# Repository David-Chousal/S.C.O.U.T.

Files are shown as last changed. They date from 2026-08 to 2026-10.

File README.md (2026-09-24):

# S.C.O.U.T.



**Santa Clara Oceanic Utilities Transmitter** — a low-cost, solar-powered, modular
**nearshore environmental monitoring platform**: one buoy carrying many sensing signals
(temperature, turbidity, dissolved oxygen, and more), with coral-reef health as its first
application.

Santa Clara University · Senior Design Capstone · 2026–2027

---

## What S.C.O.U.T. is

Coral reefs are among the most threatened ecosystems on Earth, and the instruments used to
monitor them are expensive and rarely serviced. Existing monitoring buoys cost tens of
thousands of dollars, and researchers interviewed for this project described sites where data
is physically retrieved only every few years.

S.C.O.U.T. is a small, modular, solar-powered buoy designed to be deployed adjacent to shallow
reefs and left alone. It samples a stack of environmental signals — water temperature and
turbidity today, with dissolved oxygen, light, chlorophyll, and reef soundscapes on the
sensor roadmap — stores everything locally, and transmits a summarized daily packet to a
shore station over LoRa radio, with no cellular service or internet required at the buoy.

It is deliberately built as a **platform, not a single-purpose instrument**: the sensing
payload is modular so the same buoy, power system, and shore link can be re-tasked across
reef monitoring, water-quality tracking, and satellite ground-truthing. Coral reef health is
the first mission, not the boundary. See the
[MVP System Overview](docs/overview/mvp-system-overview.md) and
[Sensor Selection](docs/engineering/sensor-selection.md) for the signal roadmap.

**Design priorities:** affordable · durable · low power · modular · minimal maintenance ·
scalable to many signals, many buoys, and many sites.

**Target:** autonomous operation for 1+ year deployments at a total system cost well below
the $5,000 figure researchers identified as the practical ceiling.

### What makes it different

Stakeholder interviews with three NOAA coral reef researchers pointed consistently at the
same gap: the highest-value contribution is not replacing existing monitoring systems, but
providing **affordable, accessible ground-truth measurements** — particularly in shallow
nearshore water, where satellite products degrade badly due to bottom reflectance and coastal
complexity. See [Stakeholder Interviews](docs/research/stakeholder-interviews.md).

---

## Status

| Subsystem | Status |
|---|---|
| Stakeholder research | ✅ Complete — 3 NOAA researchers interviewed |
| System architecture | ✅ Complete — [Engineering Design Document v0.2](docs/engineering/engineering-design-document.md) |
| Acoustic analysis pipeline | ✅ Working — validated on 8 sessions of reef recordings |
| Environmental telemetry pipeline | ✅ Working — QC, NOAA CRW Degree Heating Weeks + bleaching alerts, trends, and turbidity anomalies ([`analytics/telemetry/`](analytics/telemetry/)) |
| Firmware | 🟡 Phase 1 in progress — state machine, drivers, verified packet codec + scheduler, standby sleep, watchdog, and battery-tiered adaptive transmission; hardware bring-up next ([`firmware/`](firmware/README.md)) |
| Shore station | 🟡 In progress — simulated LoRa→CSV data path (packet codec, receiver, store) with tests ([`shore/`](shore/README.md)); real radio bring-up next |
| Live dashboard | 🟢 Deployed — static [GitHub Pages telemetry dashboard](docs/engineering/live-dashboard.md) (sample data) |
| Ask S.C.O.U.T. chat | 🟢 Live — "Fred" widget backed by a Cloudflare Worker proxy, answers from the published Hub context ([`chatbot/`](chatbot/README.md)) |
| Electrical design | 🟡 In progress — build platform decided ([ADR-0001](docs/decisions/0001-mcu-and-radio-selection.md)); charging path ([ADR-0002](docs/decisions/0002-lifepo4-charging-path.md)) and wiring/PCB pending |
| Mechanical design | 🟡 In progress — all five CAD categories documented ([SCO-50](https://linear.app/scout1/issue/SCO-50)): floatation, electronics housing, sensor/turbidity pod, stem, solar mount, in [`mechanical/cad/`](mechanical/cad/). Floatation family chosen 2026-08-17 (bolted wedge + bottom caps), first FEA pass complete ([`mechanical/test/`](mechanical/test/)). Open: buoyancy check, housing dimensions, chassis top-section access, mooring attachment hardware |
| Field deployment | 🔴 Planned — Hawaii, Phase 6 (Mar–May 2027) |

**Latest decision:** the microcontroller and LoRa radio are now settled — **Feather M0 +
RFM95 (Adafruit 3178)** as the confirmed build platform, with the ESP32-C3 + SX1262 retained
as the future production-PCB target. This unblocks firmware and wiring. See
[ADR-0001](docs/decisions/0001-mcu-and-radio-selection.md).

---

## Team

| Member | Discipline | Role |
|---|---|---|
| Isabella Rodriguez | ECEN | Hardware lead — electrical design, PCB, power system |
| John Ryan Myrdal | GENG | Field & mechanical lead — buoy structure, deployment |
| David Chousal Cantu | CSEN | Software lead — firmware, data pipeline, shore station |

**Faculty advisors:** Jes Kuczenski · Hoeseok Yang (ECEN) · Navid Shaghaghi

---

## Repository layout

```
S.C.O.U.T./
├── docs/           All project documentation (Notion-compatible Markdown)
│   ├── hub/            Knowledge Hub — facts, decisions, status, research library
│   ├── overview/       Project vision, MVP definition, status updates
│   ├── engineering/    Design document, sensor selection, architecture, shore station
│   ├── research/       Stakeholder interviews, decision matrix
│   ├── analysis/       Bioacoustic + telemetry methodology and citations
│   ├── planning/       Timeline, meeting notes, administrative
│   └── decisions/      Architecture Decision Records
├── analytics/      Acoustic + environmental-telemetry pipelines (Python) — implemented
├── shore/          Shore-station receiver, store, and packet codec (Python) — simulated path working
├── firmware/       Buoy embedded software (SAMD21/PlatformIO) — Phase 1 in progress
├── hardware/       Schematics, PCB, wiring diagrams — build platform + BOM confirmed, no schematics/PCB files yet
├── mechanical/     CAD, hull design, mooring specs — all five CAD categories documented
├── chatbot/        "Ask S.C.O.U.T." chat widget (Cloudflare Worker + Groq) — deployed
├── assets/         Brand, diagrams, and presentations
├── scripts/        Repo-level helper scripts (e.g. cross-language packet-contract guard)
└── data/           Raw audio archive (excluded from git — see Data below)
```

Each subsystem directory has its own README describing scope, current status, and what
it is blocked on.

---

## Quick start

Several components run today with no hardware: the two analytics pipelines and the shore-station
data path.

**Acoustic pipeline** — five bioacoustic indices → PCA health score → dashboard figure, on the
committed sample session:

```bash
cd analytics
pip install -r requirements.txt
python run_pipeline.py --audio_dir data/longitudinal/201708_20170801 \
                       --output data/processed/results.csv
```

**Shore data path + environmental telemetry** — simulate a buoy, push the packets through the shore
receiver into daily CSVs, then analyze them (QC, NOAA CRW Degree Heating Weeks, trends, turbidity):

```bash
cd shore
pip install -r requirements.txt
python scripts/run_loopback.py --count 48 --out ./data     # sensor sim → encode → receive → store

cd ../analytics
python run_telemetry.py --source ../shore/data --mmm 27.6 --dashboard
```

See [`analytics/README.md`](analytics/README.md) and [`shore/README.md`](shore/README.md) for the
full options, and the [live telemetry dashboard](docs/engineering/live-dashboard.md) for the deployed view.

---

## System architecture

```
   ┌─────────────────────────── BUOY ───────────────────────────┐
   │                                                            │
   │  Solar panel ──► MPPT charger ──► LiFePO₄ battery          │
   │                                        │                   │
   │                                        ▼                   │
   │  Temperature (DS18B20 ×1) ──┐    Microcontroller           │
   │  Turbidity  (SEN0189 ×1) ───┼──►  duty-cycle state machine │
   │  Hydrophone (Aquarian) ─────┘     sleep / sense / log / TX │
   │                                        │                   │
   │                          Onboard flash ┤                   │
   │                                        ▼                   │
   │                                   LoRa radio               │
   └────────────────────────────────────────┼───────────────────┘
                                            │  30-byte packet, 1×/day
                                            ▼
                        ┌─────────── SHORE STATION ───────────┐
                        │  Raspberry Pi receiver              │
                        │  Packet validation → storage        │
                        │  Statistical processing             │
                        │  Future: dashboards, cloud, ML      │
                        └─────────────────────────────────────┘
```

**Sensing.** One sensor of each modality is sited at a single point beneath the buoy, with the
electronics bay sealed above the waterline; spare temperature and turbidity units are kept for
field replacement ([ADR-0003](docs/decisions/0003-single-point-sensing.md)). A vertical
multi-depth string — measuring thermal and turbidity stratification — is a documented future
concept, not the current build. See [Sensor String Architecture](docs/engineering/sensor-string-architecture.md).

**Power.** The system sleeps most of the time, waking on an RTC alarm to sample, log, and
periodically transmit. Under sustained cloud cover it degrades gracefully: transmission
frequency drops first, local logging continues, and nonessential sensing pauses before core
operation is compromised.

**Communications.** A single summarized 30-byte packet per day (82 B is the EDD budget ceiling). Raw audio is **stored onboard
and never transmitted** — moving waveform data over LoRa is not bandwidth-feasible, and this
constraint is baked into the design.

---

## The acoustic pipeline

The [`analytics/`](analytics/README.md) pipeline is the most mature part of the project. It
processes 5-minute hydrophone recordings into reef health indicators using five established
bioacoustic indices (ACI, BI, NDSI, H, ADI), reduces them via PCA to a single Acoustic
Quality Score, and applies modified Mann-Kendall tests to detect multi-month trends.

It was developed and validated against a published reef acoustic dataset from **Sesoko
Island, Okinawa, Japan** — 8 monthly sessions spanning August 2017 to July 2018 — which
serves as a stand-in until S.C.O.U.T. collects its own recordings.

Notable design choices, documented in full in
[Coral Bioacoustic Methodology](docs/analysis/coral-bioacoustic-methodology.md):

- A **three-zone frequency model** that carves out a 200–1000 Hz mixed band and excludes it
  from NDSI, because the conventional two-way split misclassified reef fish choruses as
  anthropogenic noise.
- **Session-local PCA** for health scoring, with a separately fit global PCA for longitudinal
  trend detection — scores are explicitly not comparable across sessions.
- **Median aggregation** and an **abiotic contamination filter** to stay robust against
  wind- and rain-contaminated recordings at 1.5 m depth.

---

## The environmental telemetry pipeline

Alongside the acoustic work, [`analytics/telemetry/`](analytics/telemetry/) turns the buoy's daily
CSV records into reef-relevant indicators. It quality-controls the series (QARTOD-style range, spike,
flat-line, and gap flags), computes **NOAA Coral Reef Watch thermal-stress metrics** — HotSpot,
Degree Heating Weeks, and the 4/8/12 °C-week bleaching alert levels — detects multi-month temperature
and turbidity trends with modified Mann-Kendall, and flags turbidity anomalies. Run it with
`run_telemetry.py`; the method is written up in
[Environmental Telemetry Methodology](docs/analysis/telemetry-methodology.md), and the external
research behind it (DHW, turbidity, LoRa-over-saltwater) lives in the
[Knowledge Hub research library](docs/hub/research/sources.md).

The [`shore/`](shore/README.md) package closes the loop: a packet codec (byte-identical to the
firmware), a simulated LoRa link with configurable loss and corruption, a receiver, and a daily CSV
store — so the whole buoy → shore → analysis path runs today without hardware.

---

## Data

The raw audio archive is roughly 7 GB and is **not tracked in git**.

| What | Where | Tracked |
|---|---|---|
| Sample session (5 × 5-min WAV, ~252 MB) | `analytics/data/longitudinal/201708_20170801/` | ✅ Yes — so the pipeline is runnable on clone |
| Full 8-session archive | `analytics/data/longitudinal/` | ❌ Excluded by size |
| Bulk raw archive | `data/` | ❌ Excluded by size |
| Generated results and figures | `analytics/data/processed/` | ✅ Yes |

The full dataset is publicly available from its original authors — see the dataset citation
in [Coral Bioacoustic Methodology](docs/analysis/coral-bioacoustic-methodology.md#data-sources).
`analytics/utils/download_sesoko.py` assists with retrieval.

**Known gap:** session `201807` has 4 of 5 files; one recording failed to download. The
pipeline handles short sessions by taking the median of what is present.

---

## Documentation

Full index at [`docs/README.md`](docs/README.md). All documentation is Notion-compatible
Markdown and can be imported directly.

| Document | Why you'd read it |
|---|---|
| **[Knowledge Hub](docs/hub/README.md)** | **What's true, decided, and where the project stands right now — the always-current surface** |
| **[Conventions](docs/CONVENTIONS.md)** | **Where files go, what to name them, formats, git, units — start here before adding anything** |
| [MVP System Overview](docs/overview/mvp-system-overview.md) | What S.C.O.U.T. is and what it must do |
| [Engineering Design Document](docs/engineering/engineering-design-document.md) | The authoritative technical baseline — 22 sections including full BOM |
| [Stakeholder Interviews](docs/research/stakeholder-interviews.md) | What reef researchers actually need |
| [Coral Bioacoustic Methodology](docs/analysis/coral-bioacoustic-methodology.md) | The science behind the acoustic analysis |
| [Team Timeline](docs/planning/team-timeline.md) | Phase 0–6 plan through Hawaii deployment |
| [Decision Records](docs/decisions/README.md) | Significant open and settled decisions |

---

## Known inconsistencies

Surfaced during the August 2026 documentation audit. Resolved items are struck through with
their resolution; the remaining open ones are marked ⏳ with an owner. Recorded here rather
than silently reconciled, since resolving each required a team decision.

> The settled values now live in [`docs/hub/facts.md`](docs/hub/facts.md) (canonical) and the
> open ones in [`facts.md` → Open facts](docs/hub/facts.md#open-facts-deliberately-not-settled-yet).
> This table is the historical audit record; `facts.md` is what to check going forward.

| Issue | Detail |
|---|---|
| ~~**MCU and radio**~~ ✅ Resolved | Settled by [ADR-0001](docs/decisions/0001-mcu-and-radio-selection.md): Feather M0 + RFM95 is the build platform; ESP32-C3 + SX1262 is the future production target |
| ~~**Deployment depth**~~ ✅ Resolved | **2–8 m** max, confirmed against the actual Hawaii site (was 5–8 m). The ~30 m on the sensor-string diagram image is outdated — PNG needs re-exporting |
| ~~**LoRa range**~~ ✅ Resolved | Standardized to **~2 km line of sight** ([Adafruit RFM9x FAQ](https://learn.adafruit.com/adafruit-feather-m0-radio-with-lora-radio-module/radio-range-faq)); ~100 yd and 15–20 km figures corrected. Real over-saltwater range still to be measured in Phase 4 |
| ~~**Sensor count**~~ ✅ Resolved | [ADR-0003](docs/decisions/0003-single-point-sensing.md): one sensor per modality deployed; extra DS18B20/SEN0189 are field spares; multi-depth string deferred |
| **Hydrophone part** ⏳ ECE | Aquarian H2a-XLR (diagram) vs H2dM (BOM). **Owner: Isabella (ECE)** — [SCO-8](https://linear.app/scout1/issue/SCO-8), `Needs Decision` |
| **Dissolved oxygen status** ⏳ ECE | Wanted (meeting notes, interviews), V1.5 in sensor-selection, absent from EDD/BOM. **Owner: Isabella (ECE)** — [SCO-11](https://linear.app/scout1/issue/SCO-11), `Needs Decision` |
| ~~**Academic year**~~ ✅ Resolved | **2026–2027**. No stray 2025–2027 remains in the docs |
| ~~**Project name**~~ ✅ Resolved | **"Oceanic Utilities Transmitter"** (plural) — used consistently across all docs; no "Utility" (singular) instances remain |

---

## Related

- Team repository: [github.com/irodriguez-17/S.C.O.U.T.](https://github.com/irodriguez-17/S.C.O.U.T.)
- Project proposal deck: [`assets/presentations/SCOUT-Proposal.pptx`](assets/presentations/)

## License

Released under the [MIT License](LICENSE). Copyright (c) 2026 David Chousal Cantu,
Isabella Rodriguez, John Ryan Myrdal.

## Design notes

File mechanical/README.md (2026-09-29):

# Mechanical — Buoy Structure & Marine Design

CAD models, hull design, enclosure drawings, mooring specifications, and field test records.

> **Status:** All five CAD categories populated — floatation, electronics housing,
> sensor/turbidity housing, stem, solar mount (49 STEP/PDF files total, see
> [`cad/README.md`](cad/README.md)). **Floatation family chosen 2026-08-17** — bolted wedge
> variant with bottom caps ([`cad/floatation/README.md`](cad/floatation/README.md)), first FEA
> pass complete ([`test/`](test/README.md)). **Chassis cap + wedge cap added 2026-08-20**
> (first pass at the [SCO-53](https://linear.app/scout1/issue/SCO-53) cable-gland cap revision;
> cable routing and cap OD still open). **Design panel review 2026-08-21** — architecture
> confirmed, proceed to detailed design ([full write-up](../docs/engineering/reviews/buoy-preliminary-design-panel-review-2026-08.md)).
> Dimensioned v4 drawings (wedge, wedge cap, wedge bottom, chassis, chassis cap) landed the
> same day, giving a first-pass [mass/buoyancy budget](../docs/engineering/buoy-structural/mass-and-buoyancy-budget.md)
> and confirming the buoy's overall diameter at 18 in. **All five parts now have real
> slicer-measured weights (2026-08-24)** — whole shell ~5.49 kg, ~337.6 N net reserve buoyancy;
> see [`test/print-weight-verification-2026-08-24.md`](test/print-weight-verification-2026-08-24.md).
> **First waterproofing submersion test, 2026-08-24** — PLA sensor housing + TPU-printed O-ring
> passed ~30 hr submerged; PETG (low print quality) and the electronics housing (no bolt-joint
> washers on the tested article) both failed, see
> [`test/waterproofing-submersion-test-2026-08-24.md`](test/waterproofing-submersion-test-2026-08-24.md).
> **Electronics housing packing analysis, 2026-08-25** — real component dimensions from
> Isabella's Rev A datasheets, three candidate cylindrical layouts computed, recommended
> ~⌀100 mm × 110–130 mm (fits the existing ~4" PVC reference); see
> [Electronics Housing Packing Budget](../docs/engineering/electronics-housing-packing-budget.md).
> **Electronics housing static face-seal clamp, 2026-09-02** — new clamp + lid pair moving the
> 6 fasteners **outside** the AS568-043 O-ring boundary and sizing the groove to the standard
> ring (22.9 % squeeze, 75 % fill); closes the design panel review's lid-seal finding
> ([SCO-68](https://linear.app/scout1/issue/SCO-68),
> [`cad/electronics-housing/README.md`](cad/electronics-housing/README.md#static-face-seal-clamp--2026-09-02)).
> Printed, slight O-ring tolerance trouble, **reprint pending**
> ([SCO-105](https://linear.app/scout1/issue/SCO-105)). **Declared the housing baseline the same
> day**, superseding the end-cap-into-cylinder scheme.
> Print-structure spec (walls/infill per part) now lives in its own
> [Print Settings](../docs/engineering/buoy-structural/print-settings.md) doc; the actual FEA load values will
> land in [Force Budget](../docs/engineering/buoy-structural/force-budget.md) as their inputs arrive. Still
> open: buoyancy check + PDF-drawing reconciliation on
> [SCO-48](https://linear.app/scout1/issue/SCO-48), housing dimensions
> ([SCO-49](https://linear.app/scout1/issue/SCO-49)), chassis top section — sealing/service
> access ([SCO-68](https://linear.app/scout1/issue/SCO-68)), mooring/sensor-string attachment
> hardware ([SCO-69](https://linear.app/scout1/issue/SCO-69)), and the items below.

**Owner:** GE lead (field & mechanical)

## Design baseline

Specified in
[Engineering Design Document §4](../docs/engineering/engineering-design-document.md) and
[Sensor String Architecture](../docs/engineering/sensor-string-architecture.md).

| Element | Current design |
|---|---|
| Main housing (electronics) | **Face-seal clamp + lid** (baseline 2026-09-02) — Ø114.3 mm OD × 118.11 mm, at the ~4" Schedule 40 PVC reference. Internal sizing still open ([SCO-49](https://linear.app/scout1/issue/SCO-49)) |
| Sealing | **Static face seal, fasteners outside the O-ring boundary** — AS568-043 on the electronics housing, AS568-137 on the sensor pod. Supersedes the end-cap-into-cylinder scheme |
| Cable entry | IP68 cable glands, marine epoxy |
| Assembly | Heat-set inserts (replaced embedded nuts) |
| Geometry | Cylindrical at waterline, tapered to mooring below and antenna above |
| Sensor mounting | Modular vertical sensor string on multi-conductor cable |
| Mooring | Fixed mooring, reef-safe anchoring |

## Requirements

The structure must be waterproof, storm resistant, biofouling resistant, serviceable, and
reef-safe, with long-term mooring stability and minimal reef disturbance.

## Contents

```
mechanical/
├── cad/                        Source CAD models and exported STEP/STL
│   ├── floatation/             Hull, float, and buoyancy structure
│   ├── electronics-housing/    Sealed electronics bay enclosure
│   ├── sensor-housing/         Sensor mounting and housing
│   ├── stem/                   Structural member carrying the sensor pod underwater
│   └── solar-mount/            Solar panel mounting bracket
├── drawings/                   Dimensioned drawings, hull cross-sections
├── mooring/                    Anchor, line, swivel, and shackle specifications
├── simulations/                Re-runnable calculators — see simulations/README.md
│   └── buoy-stability/         Waterline, GM, GZ curve, self-righting, ballast sizing (+ interactive explorer)
└── test/                       Buoyancy, waterline, pressure, and submersion test records
```

## Open items

- **Deployment depth is 2–8 m** (revised 2026-08-14, was 5–8 m), confirmed against the actual
  Hawaii site — see [SCO-6](https://linear.app/scout1/issue/SCO-6). The ~30 m label on the
  sensor-string diagram image is outdated and should be re-exported.
- **Biofouling mitigation decided: Sea Hawk Smart Solution antifouling coating, 1 pint**
  (copper-free) — over copper mesh, mechanical wipers, and copper-based coatings, which
  conflict with the project's reef-safe design principle. See
  [Biofouling Antifouling Coatings](../docs/research/biofouling-antifouling-coatings.md#decision)
  ([SCO-15](https://linear.app/scout1/issue/SCO-15)).
- Waterproofing must be pressure tested at 5 m water equivalent before deployment
  ([Team Timeline](../docs/planning/team-timeline.md) Phase 5).
- Sacrificial anodes and desiccant packs are noted in meeting notes but not yet in the BOM.
- **Print material is still open** — PETG is the current default; ABS and ASA (and SLA/nylon
  for comparison) are under evaluation, one sample per material
  ([SCO-64](https://linear.app/scout1/issue/SCO-64)).
- **Mooring/sensor-string attachment hardware** on the chassis bottom is not yet designed —
  leading candidate is a stainless U-bolt with a mounting plate
  ([SCO-69](https://linear.app/scout1/issue/SCO-69)).

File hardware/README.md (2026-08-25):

# Hardware — Electrical Design

Schematics, PCB layout, wiring diagrams, and electrical test records for the SCOUT buoy.

> **Status:** Build platform and BOM confirmed (below). A Rev A prototype schematic now exists
> (`schematics/scout-reva.kicad_sch`) — ERC-clean (0 violations) and reviewed against
> manufacturer documentation. **This is schematic verification only: the Rev A electrical
> system has not yet been physically assembled or tested.** PCB layout and physical wiring
> diagrams are still not started. See **Rev A prototype schematic** below.

**Owner:** ECE lead

## Platform: dual (build vs. production)

Per [ADR-0001](../docs/decisions/0001-mcu-and-radio-selection.md) (accepted 2026-08-14) the
project runs two platforms:

- **Build platform (confirmed, purchased)** — Adafruit Feather M0 + RFM95 + Adalogger
  FeatherWing. This is what gets wired, tested, and deployed for the capstone. See
  **Confirmed hardware** below.
- **Production target (future PCB)** — the discrete ESP32-C3 + SX1262 design the
  [Engineering Design Document §5–7](../docs/engineering/engineering-design-document.md) is
  built around. Documented, not being fabricated now. See **Production-target baseline**.

## Confirmed hardware (build platform)

The team has committed to and purchased the following. Datasheet links are in the
[source index](#datasheet--source-index).

| Function | Part | Adafruit/SKU | Notes |
|---|---|---|---|
| MCU + LoRa radio | Feather M0 w/ RFM95 LoRa (900 MHz) | Adafruit 3178 | SAMD21G18 (Cortex-M0+), SX1276 radio, 32 KB SRAM |
| SD logging + RTC | Adalogger FeatherWing | Adafruit 2922 | microSD + PCF8523 RTC (stacks on the Feather) |
| Temperature | Waterproof DS18B20 (PTFE, high-temp) | Adafruit 3846 | 1-Wire, 3.0–5.0 V, 4.7 kΩ pullup |
| Turbidity | Gravity Analog Turbidity Sensor | DFRobot SEN0189 | Analog out; needs 5 V rail + level-safe ADC input |
| Battery | Rev A prototype implementation: 1S LiPo (PKCELL LP503035) via an external Adafruit PID 6106 charger/boost board | Adafruit 6106 | This is what Rev A's schematic actually implements, verified net-by-net. **Not the same as the production/deployment battery direction**, which remains a separate, open evaluation — see [ADR-0002](../docs/decisions/0002-lifepo4-charging-path.md) and [SCO-10](https://linear.app/scout1/issue/SCO-10) |

## Rev A prototype schematic

A KiCad schematic for the confirmed build platform above now exists in
[`schematics/`](schematics/), with a system interconnect diagram in [`wiring/`](wiring/) and
local copies of the relevant manufacturer documentation in [`datasheets/`](datasheets/). The
native `scout-reva.kicad_sch` is the **authoritative electrical source**; the exported PDF is
its human-readable representation; the interconnect SVG is a communication/assembly aid and
defers to the KiCad schematic if the two ever disagree.

**This is schematic-level verification, not physical validation.** KiCad ERC reports 0
violations, and the connections below were checked against manufacturer datasheets — but the
Rev A electrical system has not yet been physically built or bench-tested. Nothing here should
be read as "hardware confirmed working."

Verified schematic connections:

- **DS18B20:** powered from `3V3`; data line to Feather `D5` (`TEMP_DATA`); 4.7 kΩ pull-up
  between `3V3` and `TEMP_DATA`, matching the "4.7 kΩ pullup" note in the Confirmed hardware
  table above.
- **SEN0189:** powered from a `SYSTEM_5V` rail; analog output (`TURB_RAW`) passes through a
  10 kΩ/20 kΩ resistive divider before reaching Feather `A1` (`TURB_DATA`), scaling the
  sensor's ~0–4.5 V swing down to ~0–3.0 V — inside the SAMD21's 3.3 V ADC range. A resistive
  divider is linear and non-inverting, and the SEN0189's own manufacturer documentation
  confirms its raw analog output *decreases* as turbidity increases. This is relevant to
  [SCO-47](https://linear.app/scout1/issue/SCO-47) but does not close it — SCO-47 also
  requires the polarity to be confirmed on the bench with real clear/turbid samples, which
  hasn't happened yet. Firmware's `PIN_TURBIDITY` now matches this `A1` connection — an
  earlier mismatch (firmware read `A0`, unconnected in Rev A) was found and fixed in
  [SCO-85](https://linear.app/scout1/issue/SCO-85), merged via
  [PR #103](https://github.com/David-Chousal/S.C.O.U.T./pull/103).
- **Adalogger FeatherWing:** uses the Feather's SPI bus for the microSD card, with chip-select
  on `D10`; RTC (PCF8523) on I²C. Matches the "stacks on the Feather" note above.
- **Power path (recorded as [ADR-0006](../docs/decisions/0006-rev-a-battery-chemistry.md)):**
  the Rev A
  schematic charges a 3.7 V LiPo cell through an external Adafruit PID 6106 board — a BQ25185
  charge/power-path stage feeding a separate TPS61023 boost converter — producing a regulated
  5 V `SYSTEM_5V` rail into the Feather's `VBUS` and the SEN0189 supply. (An earlier pass of
  this document assumed the boosted rail was ~4.5 V, taken from the bare BQ25185's internal
  SYS spec; the board's actual exposed output, confirmed against Adafruit's own PID 6106
  guide, is a genuinely regulated 5 V via the separate boost IC.) This is a different chemistry
  and charge path than any option currently recorded in
  [ADR-0002](../docs/decisions/0002-lifepo4-charging-path.md) — it's real schematic evidence
  toward [SCO-10](https://linear.app/scout1/issue/SCO-10). ADR-0006 accepts it **for the Rev A
  prototype only**, so the production/deployment battery direction remains open until that
  issue is resolved and the LiFePO₄ row above stays the canonical fact.

## Production-target baseline (future PCB, per EDD)

Retained for the eventual custom board; **not** the current build.

| Function | Part | Notes |
|---|---|---|
| Microcontroller | ESP32-C3 | ~400 KB SRAM — enables on-device DSP if ever pursued |
| LoRa transceiver | Semtech SX1262 | Newer generation; lower RX/sleep current than SX1276 |
| MPPT solar charger | TI BQ25570 | Energy harvesting |
| 3.3 V buck regulator | TI TPS62840 | Always-on digital rail |
| 5 V boost regulator | TI TPS61299 | Switched measurement rail |
| Load switches | TI TPS22916 (×2) | Switched peripheral power |
| Audio ADC | TI PCM1808 | I²S audio digitization |
| Flash storage | Winbond W25Q02JV | QSPI, onboard data storage |
| Battery | LiFePO₄ | Sizing pending measured power budget |

## Datasheet / source index

| Ref | Component | Primary sources |
|---|---|---|
| REF-01 | Feather M0 LoRa (900 MHz) — Adafruit 3178 | [Product page](https://www.adafruit.com/product/3178) · pinouts/technical guide · PCB/CAD files (GitHub) |
| REF-02 | Adalogger FeatherWing — Adafruit 2922 | [Product page](https://www.adafruit.com/product/2922) · overview/pinouts guide · PCF8523 RTC datasheet (NXP) |
| REF-03 | Waterproof DS18B20 (PTFE, high-temp) — Adafruit 3846 | [Product page](https://www.adafruit.com/product/3846) — no standalone datasheet hosted; electrical specs (3.0–5.0 V, 4.7 kΩ pullup, 1-Wire) verified from the PVC-cable sibling [ID 381](https://www.adafruit.com/product/381), same DS18B20 die |
| REF-04 | Gravity Analog Turbidity Sensor — DFRobot SEN0189 | [DFRobot product page](https://www.dfrobot.com/product-1394.html) · [DFRobot wiki (specs + example code)](https://wiki.dfrobot.com/Turbidity_sensor_SKU__SEN0189) |

## Contents

```
hardware/
├── schematics/     Native KiCad schematic (authoritative) + exported PDF — populated
├── wiring/         System interconnect diagram — populated
├── datasheets/     Local manufacturer documentation for Rev A's selected components — populated
├── pcb/            Board layout, gerbers, fabrication files — not started
└── test/           Power measurements, current draw logs, bring-up records — not started
```

## Open items

- **Physical Rev A assembly and system-level testing** — the schematic is reviewed and
  ERC-clean, but nothing has been physically built or bench-tested yet.
- **Acoustic sensing is intentionally not part of Rev A.** Rev A deliberately scopes the first
  electrical baseline to controller/radio, power, temperature, turbidity, and logging. The
  hydrophone/audio front end is planned for a later revision once
  [SCO-8](https://linear.app/scout1/issue/SCO-8) resolves — this is phased development, not a
  missing requirement.
- **Battery-voltage telemetry is currently absent.** Rev A leaves the Feather's `BAT`/`VBAT`
  pin disconnected (the external pack is managed through PID 6106 instead), so the Feather's
  normal onboard battery-sense path does not measure the Rev A pack. Tracked in
  [SCO-83](https://linear.app/scout1/issue/SCO-83).
- **Battery connector polarity requires physical confirmation before connection.** The PKCELL
  LP503035 datasheet carries an explicit manufacturer "reverse the plug" warning. Tracked in
  [SCO-84](https://linear.app/scout1/issue/SCO-84).
- Sleep current target is **< 5 mA average** ([Team Timeline](../docs/planning/team-timeline.md) Phase 1, Week 3).
- LoRa and flash share the SPI bus — chip-select conflict verification is required.
- Battery and solar sizing remain provisional until the measured power budget replaces
  analytical estimates.
- **LiFePO₄ charging path (open) — [ADR-0002](../docs/decisions/0002-lifepo4-charging-path.md).**
  The Feather M0's onboard charger targets 3.7 V LiPo and is **not** compatible with the
  specified LiFePO₄ chemistry without modification. Options and the presumptive direction
  (external charger + regulated feed to `3V3`) are recorded in the ADR. Owner: ECE lead. **A
  Rev A prototype schematic now implements a different path (LiPo + external bq25185) as
  evidence toward this decision — see Rev A prototype schematic above and
  [SCO-10](https://linear.app/scout1/issue/SCO-10). Now recorded as
  [ADR-0006](../docs/decisions/0006-rev-a-battery-chemistry.md) — accepted for the Rev A
  prototype only; ADR-0002 and SCO-10 remain open for the deployment decision.**
- **Turbidity sensor is 5 V analog.** SEN0189 outputs up to ~4.5 V; the SAMD21 ADC is 3.3 V
  tolerant, so a divider or level-safe front end is required on the analog input. **Rev A's
  schematic implements a non-inverting 10 kΩ/20 kΩ divider as a candidate — see Rev A
  prototype schematic above and [SCO-47](https://linear.app/scout1/issue/SCO-47), which
  remains open pending a bench polarity test.**

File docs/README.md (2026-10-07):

# S.C.O.U.T. Documentation

All project documentation, converted to Notion-compatible Markdown. Every page here can be
imported directly into Notion with formatting intact.

---

## Start here

| If you want to… | Read |
|---|---|
| Know what's true, decided, and where the project stands right now | **[Knowledge Hub](hub/README.md)** |
| Know where a file goes or what to name it | **[Conventions](CONVENTIONS.md)** |
| Understand what S.C.O.U.T. is and why | [MVP System Overview](overview/mvp-system-overview.md) |
| See the full technical design | [Engineering Design Document](engineering/engineering-design-document.md) |
| Know what researchers actually need | [Stakeholder Interviews](research/stakeholder-interviews.md) |
| Find the schedule | [Team Timeline](planning/team-timeline.md) |
| See what's still undecided | [Decision Records](decisions/README.md) |

---

## Knowledge Hub

The always-current, always-cited surface for what S.C.O.U.T. has decided, learned, and where it
stands. **Start here for any "what's true right now?" question.** Updated on every PR
([CLAUDE.md → Standing rule 7](../CLAUDE.md#standing-rules)).

| Document | Contents |
|---|---|
| [Hub README](hub/README.md) | Front door — the six surfaces and how they fit together |
| [Canonical Facts](hub/facts.md) | The values every doc must agree with (the anti-drift keystone) |
| [Decision Log](hub/decision-log.md) | Reverse-chron ledger of every decision, linking to its full record |
| [Status](hub/status.md) + [Journal](hub/journal/) | Current subsystem state + dated history |
| [Design Notes](hub/design-notes.md) | Design-iteration narratives — what concepts were tried for a subsystem, and why |
| [Source Registry](hub/research/sources.md) | Every external work cited, with access status and reading notes |
| [Open Research Questions](hub/research/open-questions.md) | What we still need to learn, and what's been asked |

## Overview

High-level project definition and status.

| Document | Contents |
|---|---|
| [MVP System Overview](overview/mvp-system-overview.md) | Project vision, primary mission, sensing payload, power strategy, communications, mechanical design, shore station, long-term vision |
| [Project Update — July 2026](overview/project-update-2026-07.md) | Stakeholder findings, engineering progress, and a proposed broadening of scope toward nearshore environmental monitoring |

## Engineering

Technical design and component specification.

| Document | Contents |
|---|---|
| [Engineering Design Document (v0.2)](engineering/engineering-design-document.md) | **The authoritative technical baseline.** 22 sections: requirements, mechanical/electrical/firmware architecture, component selection, sensor and audio subsystems, communications, storage, operating timeline, energy budget, battery and solar sizing, assumptions, constraints, verification plan, full BOM |
| [Sensor Selection](engineering/sensor-selection.md) | Candidate sensors tiered V1 / V1.5 / future, with cost, interface, power draw, and vendor links |
| [Sensor String Architecture](engineering/sensor-string-architecture.md) | Vertical multi-depth sensor string layout and placement rationale |
| [On-Board CSV Data Schema](engineering/data-schema.md) | The microSD log format — columns, units, timestamps; the firmware ↔ shore-station/analytics contract |
| [Hardware/Software Integration Runbook](engineering/integration-runbook.md) | **How the software gets onto the hardware** — toolchain, what programs what, and the staged bring-up from bench to field, with a PASS gate at every step. Written to be executed by a Claude session. |
| [Shore Station (Raspberry Pi)](engineering/shore-station.md) | The Raspberry Pi base station — LoRa reception, packet decode, storage, analytics; the canonical Pi reference |
| [Live Dashboard (GitHub Pages)](engineering/live-dashboard.md) | How the shore Pi republishes a self-contained static telemetry dashboard to GitHub Pages — no server |
| [Buoy Structural Engineering](engineering/buoy-structural/) | Load equations, mass/buoyancy budget, force tracking, and print settings — grouped together since they cite each other constantly. See the [folder's own index](engineering/buoy-structural/README.md) for what's inside |
| [Electronics Housing Packing Budget](engineering/electronics-housing-packing-budget.md) | Real component dimensions from Isabella's Rev A datasheets, three candidate cylindrical packing layouts, and the resulting minimum diameter/length/volume for each |
| [Design Panel Reviews](engineering/reviews/) | Panel-review write-ups (raw source PDF + Markdown transcription) of subsystem architecture — currently the [buoy preliminary design panel review](engineering/reviews/buoy-preliminary-design-panel-review-2026-08.md) |

## Research

External input and decision tracking.

| Document | Contents |
|---|---|
| [Stakeholder Interviews](research/stakeholder-interviews.md) | Summer 2026 interviews with three NOAA coral reef researchers; consolidated findings and recommended direction |
| [Market Analysis](research/market-analysis.md) | Is there a market beyond the capstone? Scientific and defence ocean monitoring sized against verifiable sources; what is and is not defensible; and §8, the operational sequence to a profitable company — IP gate, buyer pivot, 24-month plan with kill criteria |
| [Systems Decision Matrix](research/systems-decision-matrix.md) | Master taxonomy of every research and design decision area across all disciplines |

## Analysis

Data science methodology for the acoustic pipeline.

| Document | Contents |
|---|---|
| [Coral Bioacoustic Methodology](analysis/coral-bioacoustic-methodology.md) | Full scientific methodology: index definitions, trend detection, seasonal normalization, disturbance detection, health classification, data sources, limitations, and citations |
| [Environmental Telemetry Methodology](analysis/telemetry-methodology.md) | Temperature/turbidity/battery analysis: QC, daily aggregation, NOAA Coral Reef Watch DHW & bleaching alerts, Mann-Kendall trends, turbidity anomalies, with citations |

Implementation lives in [`analytics/`](../analytics/README.md).

## Planning

Schedule, meetings, and administrative records.

| Document | Contents |
|---|---|
| [Team Timeline](planning/team-timeline.md) | Phase 0–6 work plan from kickoff through Hawaii deployment, with parallel per-discipline tracks |
| [Meeting Notes](planning/meeting-notes.md) | Running team design meeting notes |
| [Gantt Chart and WBS](planning/gantt-and-wbs.md) | How the CSV, script and PDF task plan fit together |
| [Senior Design Time Log](planning/time-log.md) | John Ryan Myrdal's hours on S.C.O.U.T., estimated for the past and reported going forward |
| [Signature Page](planning/signature-page.md) | SCU capstone declaration — team members and faculty advisors |

## Decisions

| Document | Contents |
|---|---|
| [Decision Records](decisions/README.md) | Architecture Decision Records — significant, hard-to-reverse choices |

---

## Conventions

**Full reference: [CONVENTIONS.md](CONVENTIONS.md)** — naming, file placement, formats, git,
units, citations, and a teammate FAQ.

The rules that apply specifically to documents in this directory:

- **One H1 per page.** Notion uses it as the page title.
- **Summary callout at the top** of each converted document, naming the original source file.
- **Relative links** between documents so navigation survives both GitHub and Notion import.
- **Tables use GFM pipe syntax** — Notion's importer does not reliably parse HTML tables.
- Source documents were converted from `.docx` via `pandoc -t gfm`, then cleaned. Original
  binaries are not retained; this Markdown is the source of truth. The one exception is
  [`assets/presentations/SCOUT-Proposal.pptx`](../assets/presentations/), kept because slide
  decks convert poorly.

## Known documentation issues

Contradictions found during the August 2026 documentation audit. Resolved items are struck
through with their resolution; the remaining open ones are marked ⏳ with an owner:

| Issue | Detail |
|---|---|
| ✅ ~~MCU and radio conflict~~ | **Resolved** by [ADR-0001](decisions/0001-mcu-and-radio-selection.md) (2026-08-14): Feather M0 + RFM95 build platform, ESP32-C3 + SX1262 future production target |
| ✅ ~~Deployment depth~~ | **Resolved: 2–8 m** max, confirmed against the actual Hawaii site (was 5–8 m). The ~30 m on the sensor-string diagram image is outdated and should be re-exported |
| ✅ ~~LoRa range~~ | **Resolved: ~2 km line of sight** ([Adafruit RFM9x FAQ](https://learn.adafruit.com/adafruit-feather-m0-radio-with-lora-radio-module/radio-range-faq)); ~100 yd / 15–20 km corrected. Actual over-saltwater range to be measured in Phase 4 |
| ✅ ~~Sensor count~~ | **Resolved** by [ADR-0003](decisions/0003-single-point-sensing.md): one sensor per modality deployed; extras are field spares; multi-depth deferred |
| **Hydrophone part** ⏳ | Diagram cites Aquarian H2a-XLR; EDD BOM specifies H2dM. **Owner: Isabella (ECE)** — [SCO-8](https://linear.app/scout1/issue/SCO-8), `Needs Decision` |
| **Dissolved oxygen status** ⏳ | Wanted (meeting notes, interviews), V1.5 in sensor-selection, absent from EDD/BOM. **Owner: Isabella (ECE)** — [SCO-11](https://linear.app/scout1/issue/SCO-11), `Needs Decision` |
| ✅ ~~Academic year~~ | **Resolved: 2026–2027.** No stray 2025–2027 remains in the docs |
| **Audio over LoRa** | EDD states raw audio is stored onboard and never transmitted. Any plan to transmit waveform data contradicts the design baseline and is not bandwidth-feasible |

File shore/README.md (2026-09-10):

# Shore — Raspberry Pi data path

Shore-station software: the LoRa packet codec, a hardware-free sensor simulator, a mock LoRa
link, a schema-validated CSV store, and the receiver that ties them together.

Runtime and role are documented in
[docs/engineering/shore-station.md](../docs/engineering/shore-station.md). The buoy is a
Feather M0; **this code runs on the Raspberry Pi** (see
[ADR-0001](../docs/decisions/0001-mcu-and-radio-selection.md)).

> **Status:** simulated end-to-end path working with **no hardware**, plus a real SX1276
> backend (`radio.Rfm9xLink`) and a systemd service — both ⚠️ **written but never run against
> hardware**. Both sides implement the `LoRaLink` protocol in
> [`scout_shore/link.py`](scout_shore/link.py), so switching is a `--link` flag, not a code
> change.

## The path

```
sensor simulator → packet.encode → MockLoRaLink (loss/corruption)
    → Receiver: packet.decode → schema.validate → CsvStore (daily CSV)
```

Everything conforms to the
[On-Board CSV Data Schema](../docs/engineering/data-schema.md), so shore-decoded data and
retrieved on-buoy data share one format and one analytics path.

**Writes are idempotent.** The buoy transmits each daily packet several times without waiting
for an acknowledgement (blind repetition — see `firmware/lib/scout_link`), so the same reading
legitimately arrives more than once. `CsvStore` keys on `(buoy_id, record_seq)` and skips
copies it has already stored, seeding that key set from the daily file on disk so a restarted
shore station does not re-admit them. `Receiver.stats.duplicates` counts the skips: they are
expected traffic, not errors. Without this, repeats would triple every row and inflate the
completeness figure in `analytics/telemetry/qc.py`, masking real gaps.

## Layout

```
shore/
├── scout_shore/
│   ├── packet.py       LoRa packet codec (encode/decode + CRC) — the firmware↔shore contract
│   ├── schema.py       Reading → CSV row (data-schema.md) + row/file validator
│   ├── simulator.py    synthetic readings (diurnal temp, turbidity events, battery)
│   ├── store.py        append rows to per-day CSV files
│   └── receiver.py     MockLoRaLink + Receiver (decode → validate → store, with stats)
├── scripts/
│   └── run_loopback.py end-to-end demo
└── tests/              unittest suite (stdlib only)
```

## Run

```bash
cd shore

# End-to-end demo: 1 day of readings, 5% loss, 2% corruption
python scripts/run_loopback.py --count 48 --loss 0.05 --corrupt 0.02 --out ./data

# Tests (stdlib unittest — no install needed; pytest also works)
python -m unittest discover -s tests -v
```

## Deploying on the Pi

```bash
# One-time: the radio backend is the shore station's only third-party dependency.
pip install adafruit-circuitpython-rfm9x

sudo cp shore/deploy/scout-shore.service /etc/systemd/system/
sudo systemctl daemon-reload
sudo systemctl enable --now scout-shore
journalctl -u scout-shore -f
```

The unit assumes the repo is at `/home/pi/S.C.O.U.T.` and runs as `pi`; adjust
`WorkingDirectory` and `User` if yours differs.

**It restarts unconditionally, by design.** `Restart=always` with the start-limit disabled: an
unattended station on a coastline will not be restarted by hand, and the buoy transmits blind,
so if nothing is listening neither end raises an alarm. A radio that throws is caught, counted,
and retried with a widening backoff capped at 60 s, so a dead link never pins the CPU and a
recovered one is picked up promptly. `SIGTERM` is a clean stop, so `systemctl stop` and reboots
never interrupt a CSV write.

### Where received data has to go

```bash
python scripts/run_receiver.py --link rfm9x --out data-live   # what the unit runs
```

`data-live/` is **tracked in git** and is what the public dashboard publishes from — see
[`data-live/README.md`](data-live/README.md). `data/` is gitignored scratch that CI regenerates
from the simulator on every Pages build. Writing received data to `data/` would mean it is
never committed *and* overwritten within the hour, so the site would keep showing sample data
with no error anywhere. The choice between the two is made in
[`scout_shore/publish.py`](scout_shore/publish.py), which is tested; real data always wins and
is never labelled as a simulation.

## Recovering a retrieved SD card

The buoy transmits each daily packet a few times and never waits for an acknowledgement. If
shore misses every copy — a power cut, a storm, the station down for maintenance — that reading
exists **only** on the buoy's SD card. And even the readings that did arrive are lossy: a
30-byte packet cannot carry `turbidity_v`, `turbidity_ntu` or the audio filename, so those cells
are empty in the shore CSV while the card has them.

```bash
# Inspect a card before touching anything:
python scripts/import_sd_card.py --card /Volumes/SCOUT --into data-live --dry-run

# Merge it in:
python scripts/import_sd_card.py --card /Volumes/SCOUT --into data-live
```

Merging is on `(buoy_id, record_seq)` — the same idempotency key the receiver uses for blind
repeats — so **running it twice is a no-op**. The card wins cell by cell where it holds more,
but a blank cell on the card never overwrites a value shore received: a row half-written at the
moment of power loss must not erase a reading that arrived intact over the radio. Existing shore
rows the card lacks are kept, because a card pulled mid-deployment is a partial record and
treating it as authoritative for *absence* would delete history.

Rows that cannot be keyed are reported on stderr and the command exits non-zero. They are never
silently skipped — a row on the card we failed to import is exactly the loss this tool exists to
prevent.

## Contract note

`packet.py` is the **verified wire format** (30 bytes, well under the 82-byte daily budget
ceiling in EDD §10 — see [`docs/hub/facts.md`](../docs/hub/facts.md) for why those are two
different numbers, not a contradiction). It's mirrored byte-identical by the firmware C
encoder, CI-enforced via a golden vector (`firmware/test/test_packet`). `turbidity_v` still
uses provisional ADC constants pending the analog front-end design.

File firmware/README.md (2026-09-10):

# Firmware — Buoy Embedded Software

Embedded firmware for the SCOUT buoy: sensor sampling, duty-cycle scheduling, local logging,
and LoRa transmission.

> **Status:** **Phase 1 scaffold.** The project structure, the duty-cycle state machine, the
> hardware-driver wrappers, and the build/test setup are in place. The **pure-logic core is
> real and verified** (packet codec byte-identical to the shore decoder; scheduling math
> unit-tested). Hardware bring-up on the bench — real sensor reads, SD, LoRa, and true SAMD21
> standby sleep — is the next step, per [Team Timeline](../docs/planning/team-timeline.md) Phase 1.

## Platform & toolchain

Confirmed build platform: **Adafruit Feather M0 with RFM95 LoRa, 900 MHz (Adafruit 3178)**,
paired with the **Adalogger FeatherWing (Adafruit 2922)** for microSD logging and a PCF8523
real-time clock.

- **Toolchain:** Arduino IDE or PlatformIO, **Arduino SAMD core** (SAMD21G18, ARM Cortex-M0+).
- **LoRa driver:** RadioHead `RH_RF95`.
- **RTC:** PCF8523 on the Adalogger (use `RTClib`), not the DS3231 named in older timeline drafts.
- **Hard constraint — 32 KB SRAM.** A 5-minute recording cannot be held in memory, so audio
  is streamed to microSD in small blocks and **all acoustic-index computation happens
  shore-side** in [`analytics/`](../analytics). The buoy records and stores audio; it does not
  analyze it on-device.

The ESP32-C3 + SX1262 in the [Engineering Design Document](../docs/engineering/engineering-design-document.md)
is the *future production-PCB* target, **not** what firmware targets today. Code written
against the Arduino SAMD21 core would need porting to ESP-IDF if that board is ever built.
See [ADR-0001](../docs/decisions/0001-mcu-and-radio-selection.md).

## Intended responsibilities

Per [Engineering Design Document §12](../docs/engineering/engineering-design-document.md):

- Sensor management — temperature (DS18B20, 1-Wire), turbidity (SEN0189, analog), audio (PCM1808, I²S)
- Duty-cycle state machine — `Sleep → Wake → Sense → Log → Battery check → Transmit → Sleep`
- Deep sleep scheduling and RTC alarm wake
- Battery voltage monitoring, with transmission skipped below threshold
- Local logging to microSD (Adalogger FeatherWing)
- LoRa packet assembly and transmission (30-byte daily payload; 82 B is the EDD budget ceiling)
- Watchdog timer and error recovery
- State of Health telemetry — battery voltage, internal temperature, humidity

## Layout

```
firmware/
├── platformio.ini          Feather M0 build + native (host) test envs
├── src/
│   ├── main.cpp            Duty-cycle state machine: Sleep→Wake→Sense→Log→Battery→TX→Sleep
│   ├── config.h            Pin map, cadence, thresholds  (⚠ confirm pins with ECE)
│   └── drivers/            Thin hardware wrappers (DS18B20, turbidity, PCF8523, SD, RFM95, battery)
├── lib/                    Hardware-free, host-testable libraries:
│   ├── scout_packet/       LoRa packet codec — byte-identical to shore/scout_shore/packet.py
│   ├── scout_scheduler/    Duty-cycle timing math (next wake, daily TX, battery gate, audio hours)
│   └── scout_link/         Blind-repetition delivery policy + watchdog-headroom guard
├── test/                   Unity unit tests (run on the host)
│   ├── test_packet/        Encoder vs the shore golden vector + CRC + fixed-point helpers
│   ├── test_scheduler/     Wake grid, daily-TX cadence, battery gate, audio scheduling
│   └── test_link/          Repeat counts by power mode, gap widening, watchdog headroom
└── docs/                   pin-assignments.md, flashing-guide.md
```

## Build & test

```bash
pio run                 # build for the Feather M0
pio run -t upload       # flash (double-tap RESET for the bootloader)
pio test -e native      # run the pure-logic unit tests on your computer (no board needed)
```

## What's real vs. scaffold

- **Real & verified:** `scout_packet` (encoder proven byte-identical to the Python shore
  decoder) and `scout_scheduler` (unit-tested). The state machine and CSV row format
  ([data-schema.md](../docs/engineering/data-schema.md)) are wired end to end.
- **Implemented, pending bench verification:**
  - **Standby sleep** — real SAMD21 deep sleep (`ArduinoLowPower`) woken by the PCF8523
    countdown-timer INT on `PIN_RTC_INT`, with a flag-clear on wake so it re-arms each
    interval. Needs the INT wired and a current measurement to confirm the low-power draw.
  - **Watchdog** — the SAMD21 WDT (`Adafruit_SleepyDog`, ~16 s) guards each active cycle and
    init; a hang resets the buoy so it recovers on its own. Disabled during standby (its
    timeout is far shorter than the 30-min interval) and re-armed on wake. A watchdog reset is
    detected at boot (`PM->RCAUSE`) and logged.
  - **Adaptive transmission (graceful degradation)** — a power mode derived from battery
    voltage (`scout_power_mode`): **NORMAL** (all sensing, transmit each interval) →
    **CONSERVE** (audio off, transmit ×`TRANSMIT_CONSERVE_FACTOR` less often) → **CRITICAL**
    (temperature + logging only; no turbidity, audio, or TX). Core temperature always logs.
    The `POWER_CONSERVE` flag marks throttled rows so shore can see it. Pure logic in
    `scout_scheduler`, unit-tested; thresholds in `config.h` (provisional, ADR-0002).
  - **Retained state across resets** — `record_seq` and `last_tx_epoch` live in a no-init RAM
    section (magic-guarded) that the C startup doesn't clear, so a watchdog/system reset keeps
    the counter monotonic and doesn't re-send the daily packet. RAM-based: a full power loss
    still cold-starts (the PCF8523 has no user NVRAM; SD/flash persistence was declined to
    avoid wear for the rarer power-loss case). Verify by inducing a reset and confirming
    `resume_seq` continues in the boot log.
  - **Daily-packet delivery reliability** — CR 4/8 forward error correction plus **blind
    repetition**: the same frame goes out `SCOUT_LINK_REPEATS_NORMAL` times, spaced with
    widening gaps, and the buoy never listens for an acknowledgement. A lost daily packet
    costs timeliness, not data (the full record is on the SD card), so ACKed retransmit would
    buy little and risks an avalanche across a multi-buoy deployment. Repeat count degrades
    with the power mode like everything else (3 in NORMAL, 1 in CONSERVE, 0 in CRITICAL).
    The shore station deduplicates on `(buoy_id, record_seq)`, so copies collapse to one row.
    The modem runs **BW 500 kHz · SF12 · CR 4/8 · +11 dBm** — widened from BW125/SF7 on
    2026-09-01 because 47 CFR §15.247 requires either a ≥500 kHz bandwidth or ≥50-channel
    hopping, and the old single-channel BW125 config met neither (SCO-19). See the note in
    `drivers/lora_link.h` and [`facts.md`](../docs/hub/facts.md). Policy is pure logic in `scout_link`, unit-tested, including a
    guard that the repeat schedule cannot outrun the watchdog. Needs a real range test
    (SCO-14) to confirm the delivery gain over the air.
- **Scaffold (Phase 1 bench work):** the driver wrappers call the real libraries but need
  on-hardware verification and pin confirmation; **audio** (PCM1808/hydrophone) is a scheduled
  hook only — it's a V1 stretch, not on the confirmed Feather build.

## Notes

- **The packet layout is the contract with the shore station.** `lib/scout_packet` mirrors
  `shore/scout_shore/packet.py` exactly; `test_packet` enforces it against a golden vector
  generated by the Python side. Change one, change both, and bump `SCOUT_PACKET_VERSION`.
- The CSV log format is specified in
  [data-schema.md](../docs/engineering/data-schema.md) — the writer↔reader contract with
  `analytics/`.
- Pure-logic code stays in `lib/` (no Arduino includes) so it compiles and tests on the host.

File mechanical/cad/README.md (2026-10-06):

# CAD

Source CAD models and exported STEP/STL, organized by subsystem.

| Folder | Contents |
|---|---|
| [floatation/](floatation/) | Hull, float, and buoyancy structure |
| [electronics-housing/](electronics-housing/) | Sealed electronics bay enclosure |
| [sensor-housing/](sensor-housing/) | Sensor mounting and housing |
| [stem/](stem/) | Structural member carrying the sensor pod underwater |
| [solar-mount/](solar-mount/) | Solar panel mounting bracket |

**Full assembly (current): [`full-buoy-assembly-v7.step`](full-buoy-assembly-v7.step)**, Fusion "DFM Assembly 2", exported 2026-10-06 (John Ryan, "updated full STEP file for buoy"). It keeps the same parts as v6 and adds **two new bodies dated 2026-10-05**, which are consistent with the larger flange electronics housing ([electronics-housing README](electronics-housing/README.md#larger-flange-housing-on-the-chassis-lip--2026-10-06-drawing-in-repo-step-not-yet)). That reading is inferred from the file's part list, not stated by John. The assembly was not diffed against v6 beyond its part list, so any other changes are unrecorded. The stability calculator and freeboard model still read the v6 geometry until re-run.

**Previous full assembly (v6): [`full-buoy-assembly-v6.step`](full-buoy-assembly-v6.step)**, superseded 2026-10-06 by v7. Fusion "DFM Assembly 2", exported 2026-09-29. It has **1.5 in wedge-bottom caps**, the 7.0 in chassis, the six v5 wedges, the **24 in 316 ballast pipe (4816K51) in a 6040T56 slip-on mount** at the chassis bottom, and six tentative alignment pegs between caps and wedges. No electronics housing, solar mount, pod, or lead is modelled yet. The stability calculator reads its cap geometry ([`mechanical/simulations/buoy-stability/`](../simulations/buoy-stability/README.md)).

**Previous full assembly:** [`full-buoy-assembly-v5.step`](full-buoy-assembly-v5.step) is the whole buoy
as one STEP (John Ryan, Fusion "DFM Assembly", exported 2026-09-25). It holds the v5 floatation
ring, chassis and caps, cable routing, and the `3076T33` stand-in mooring ring, and it is the model
the 2026-09-25 FEA re-check ran on. It lives here rather than in a subsystem folder because it spans
all of them.

Versioned filenames only for physical artifacts (`part-name-v2.step`) — see
[CONVENTIONS.md § Versions](../../docs/CONVENTIONS.md#versions).

## Native source — split across two tools

**Resolved 2026-08-25** (was flagged 2026-08-24 below): CAD work is deliberately split by tool,
not migrating wholesale off Onshape.

- **Part geometry — Onshape.** Individual part modeling (wedges, chassis, housings, all of it)
  continues in Onshape, same as always.
- **Assembly — moving to Fusion 360.** John is gradually shifting assembly work (fitting parts
  together, checking clearances/interferences, the whole-buoy view) to Fusion 360. This is a
  slow, ongoing move, not a cutover — expect both tools in active use for a while.
- **FEA — Fusion 360**, unchanged and already documented in
  [`mechanical/test/README.md`](../test/README.md).

Per [CONVENTIONS.md § File formats](../../docs/CONVENTIONS.md#file-formats), the native-source
reference for cloud CAD tools is a share link, not a repo file. For part geometry, that's still:

**[S.C.O.U.T. mechanical — Onshape document](https://cad.onshape.com/documents/dde7d770a7f2e84b52bc9fb5/w/ae73f9a2c15a69a24bbaec2a/e/c10fd1132e8b0e9eb908d70b)**

This one Onshape document holds the whole project's part geometry — floatation, sensor housing,
electronics housing, all of it — not a separate document per subsystem. Internal tab/part
naming inside it doesn't always match this repo's file names (Onshape's auto-generated "Copy 1
Copy 2" naming); the `README.md` in each subsystem folder here is the clearer map of what each
STEP export is. Fusion assembly files aren't yet tracked with their own share link here — add
one once the assembly move is far enough along to be the thing a teammate should actually open.

<details>
<summary>Flagged 2026-08-24, resolved 2026-08-25 (kept for the record)</summary>

John mentioned switching primary CAD modeling work to Fusion 360 in the
[2026-08-24 SCOUT Weekly](../../docs/planning/meeting-notes.md#2026-08-24--scout-weekly)
("because it's just better"), without saying whether that meant all modeling or just FEA (Fusion
was already the documented FEA tool). Left open rather than guessed at. Clarified 2026-08-25:
part geometry stays in Onshape; only assembly is moving to Fusion, gradually.

</details>

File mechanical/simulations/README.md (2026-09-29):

# Mechanical Simulations and Calculators

> **Summary** — Re-runnable engineering calculators for the buoy: code, inputs, and dated results.
> Open a calculator's `README.md` for what it computes and how to run it. The **newest results
> folder is always the current answer**; older dated folders are kept as history.
>
> Part of [`mechanical/`](../README.md). Method write-ups live in
> [`docs/engineering/buoy-structural/`](../../docs/engineering/buoy-structural/README.md).

---

## Calculators

| Calculator | Computes | Current results | Interactive |
|---|---|---|---|
| [`buoy-stability/`](buoy-stability/README.md) | Waterline, freeboard, GM, full righting-arm curve (0–180°), self-righting check, minimum ballast, sweeps over housing mass / cap height / ballast depth | [`results/2026-09-29/`](buoy-stability/results/2026-09-29/) | [`stability-explorer.html`](buoy-stability/results/2026-09-29/stability-explorer.html) (download and open in a browser) |

## How "current" is marked

- **Code is never versioned by filename** ([CONVENTIONS § Versions](../../docs/CONVENTIONS.md#versions)).
  Each calculator has one live copy; git history holds earlier states, and each calculator's
  README keeps a dated changelog.
- **Results are dated folders:** `results/YYYY-MM-DD/`. The latest date is current, and this
  table links it. Re-running a calculator writes a new dated folder; don't edit old ones.
- **Inputs change → re-run → new folder → update this table** in the same PR.

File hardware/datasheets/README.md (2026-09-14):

# Datasheets

Local manufacturer documentation for components in the Rev A prototype schematic
([`../schematics/`](../schematics/)). These supplement, rather than replace, the online
[Datasheet / source index](../README.md#datasheet--source-index) in `hardware/README.md`.

| File | Component |
|---|---|
| `adafruit-feather-m0-radio-with-lora-radio-module.pdf` | Feather M0 + RFM95 (build platform, per [ADR-0001](../../docs/decisions/0001-mcu-and-radio-selection.md)) |
| `ti-sx1276-77-78-79-lora-transceiver.pdf` | SX1276 radio chip underlying the RFM95 module |
| `adafruit-adalogger-featherwing.pdf` | Adalogger FeatherWing guide (RTC + microSD) |
| `adafruit-adalogger-featherwing-reference-schematic.png` | Adafruit's own reference schematic for the Adalogger FeatherWing — confirms the PCF8523 RTC and SD chip-select on `D10` |
| `maxim-ds18b20-digital-thermometer.pdf` | DS18B20 temperature probe |
| `dfrobot-sen0189-turbidity-sensor.pdf` | SEN0189 turbidity sensor — includes the manufacturer's polarity statement referenced by [`facts.md`](../../docs/hub/facts.md#sensing-single-point-per-modality--see-adr-0003) and [SCO-47](https://linear.app/scout1/issue/SCO-47) |
| `dfrobot-sen0189-probe-dimension.png` | SEN0189 **probe body** mechanical drawing (as opposed to the adapter board covered by the datasheet above) — manufacturer drawing, saved 2026-09-13 from [DFRobot's official wiki](https://wiki.dfrobot.com/Turbidity_sensor_SKU__SEN0189) → `Probe_Dimension` link (hosted at `github.com/Arduinolibrary/DFRobot_Turbidity_sensor`). Feeds [Sensor Pod Packing Budget](../../docs/engineering/sensor-pod-packing-budget.md) |
| `ti-bq25185-battery-charger.pdf` | BQ25185 charger IC used on the Rev A schematic's external charger board — bare chip datasheet only; see gap below |
| `pkcell-lp503035-lipo-battery.pdf` | PKCELL LiPo battery used in the Rev A prototype |

## Not a decision record

These files support the Rev A schematic review; they are not, by themselves, a resolution of
any open issue. In particular:

- **[SCO-10](https://linear.app/scout1/issue/SCO-10)** (LiFePO₄ charging path) and
  **[ADR-0002](../../docs/decisions/0002-lifepo4-charging-path.md)** remain open. The Rev A
  schematic's LiPo + external-charger path is evidence toward a decision, not the decision
  itself.
- **[SCO-47](https://linear.app/scout1/issue/SCO-47)** (SEN0189 non-inverting front end)
  remains open. The datasheet here confirms the sensor's raw polarity and the schematic
  implements a non-inverting divider, but the issue's bench-test acceptance criterion has not
  been performed.

## Excluded on purpose

Not included in this directory because they are not part of the Rev A design:

- **DS3231 RTC documentation** — Rev A's Adalogger FeatherWing uses a **PCF8523** RTC,
  confirmed by Adafruit's own reference schematic above. The DS3231 material documents a
  different/earlier candidate component.
- **IRFZ44N MOSFET datasheet** — earlier candidate part, not in Rev A.
- **LC709203F battery monitor datasheet** — earlier candidate part, not in Rev A.

## Documentation gaps

Not fabricated or substituted — flagged as missing until authoritative sources are available:

- **Adafruit bq25185 board-level guide.** Only the bare TI BQ25185 chip datasheet is on file.
  The Rev A schematic's charger symbol represents Adafruit's breakout board, not the bare IC —
  board-specific behavior (VIN vs. VUSB, boost-enable default state) is not yet confirmed
  against Adafruit's own documentation.
- **FlexSolar 10W panel manufacturer specification.** No authoritative manufacturer datasheet
  or manual is on file. A retail listing is not treated as a datasheet and is not included
  here.

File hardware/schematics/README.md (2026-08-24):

# Schematics

**Authoritative source:** `scout-reva.kicad_sch` (+ `scout-reva.kicad_pro` to open the project
cleanly in KiCad). `scout-reva-schematic.pdf` is a human-readable export of the same design —
if the two ever disagree, the `.kicad_sch` wins.

Rev A status: ERC-clean (0 violations), reviewed against manufacturer documentation.
**Not yet physically built or tested** — see [../README.md](../README.md) and
[ADR-0001](../../docs/decisions/0001-mcu-and-radio-selection.md).

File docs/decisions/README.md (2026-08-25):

# Architecture Decision Records

Significant, hard-to-reverse decisions are recorded here as ADRs — one file per decision,
numbered sequentially and never deleted.

## Why

Project documents currently disagree with each other on several points (see ADR-0001). An
ADR makes the reasoning behind a choice durable, so that six months later the team can see
not just *what* was decided but *why*, and what alternatives were rejected.

Routine choices belong in the
[Systems Decision Matrix](../research/systems-decision-matrix.md). Write an ADR when the
decision is expensive to reverse, contested between documents or people, or constrains
multiple subsystems.

## Index

| ID | Decision | Status |
|---|---|---|
| [0001](0001-mcu-and-radio-selection.md) | Microcontroller and LoRa radio selection | 🟢 Accepted |
| [0002](0002-lifepo4-charging-path.md) | LiFePO₄ charging path on the Feather M0 | 🟡 Open |
| [0003](0003-single-point-sensing.md) | Single-point sensing per modality (multi-depth deferred) | 🟢 Accepted |
| [0004](0004-reef-safe-anchoring-and-mooring.md) | Reef-safe anchoring and mooring approach | 🟢 Accepted |
| [0005](0005-v1-sensing-payload.md) | V1 sensing payload — temperature, turbidity, hydrophone; DO excluded | 🟢 Accepted |
| [0006](0006-rev-a-battery-chemistry.md) | Rev A prototype battery chemistry and power path (LiPo + external bq25185) | 🟢 Accepted — Rev A scope only; deployment chemistry still open in 0002 |

**Status values:** 🟡 Open · 🟢 Accepted · 🔵 Superseded · ⚪ Deprecated

## Format

Copy this skeleton for new records:

```markdown
# ADR-NNNN — Short title

- **Status:** 🟡 Open
- **Date raised:** YYYY-MM-DD
- **Owners:** who decides
- **Blocks:** what cannot proceed until this resolves

## Context
What situation forces a decision. Cite the conflicting sources.

## Options
Each option with honest pros and cons.

## Decision
The call, once made — or "Not yet made."

## Consequences
What follows, including the costs accepted.

## References
Links to the documents and data behind the decision.
```

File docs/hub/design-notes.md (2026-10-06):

# Design Iteration Notes

> **Summary** — Index of design-iteration narratives: the concepts tried, why, and what was
> learned, for parts of the project with a real iteration history worth preserving. This is the
> raw process record — [`facts.md`](facts.md) holds only the current settled values, and this
> surface is not itself a source of canonical facts.
>
> Part of the [Knowledge Hub](README.md).

---

The full narrative for each row lives with the actual work (usually a CAD/firmware folder's own
`README.md`), not duplicated here. This is the index, so the history is discoverable from one
place even though the detail is scattered across the repo.

## How to add a row

Add to the top of the table. Keep the summary to one or two lines — the full story belongs in
the linked doc, written up as it's told to you, not paraphrased away.

```
| 2026-08-20 | hardware | Power board | Tried buck converter X, switched to Y for efficiency at low load | [hardware/pcb/power/README.md](../../hardware/pcb/power/README.md) |
```

---

## Log

| Date | Area | Subsystem | Summary | Full notes |
|---|---|---|---|---|
| 2026-09-23 | mechanical | Floatation, wedge bottom | With the medium Prusa failed and a full wedge bottom taking over a day to print, John split the lean v5 wedge bottom into two 30° halves with one clean radial cut down the center so it fits a Prusa Mini. Half 1 printed with poor bottom layers (nozzle drag, feed resistance). The split is a print workaround for now, and the one-piece part stays the baseline | [print log](../../mechanical/test/wedge-bottom-split-print-2026-09-23.md), [floatation README](../../mechanical/cad/floatation/README.md#split-into-two-parts-for-printing--2026-09-23) |
| 2026-09-24 | mechanical | Floatation, wedge bottom | The Prusa Mini split-half prints failed repeatedly (bed adhesion, Z calibration off), so the split has no working printer. The larger printer printed wedges well once PTFE-tube feed resistance was fixed. The one-piece wedge bottom stays the baseline | [print log](../../mechanical/test/wedge-bottom-split-print-2026-09-23.md#outcome-2026-09-24) |
| 2026-09-25 | mechanical | Wedge drop test + STEP geometry check | John dropped a single printed v5 wedge with no deformation and closed SCO-71 on that plus the v5 FEA. Separately, measuring the STEP files showed the wedge bottom is **3.00 in tall** (the freeboard model assumes 2 in), with a **1.084 L** foam cavity and **1.348 L** envelope (v4: 0.820 L / 1.255 L). The model under-counts displacement by ~4 L, so the buoy floats higher than documented. The stack rebuild is SCO-124. | [Drop test](../../mechanical/test/wedge-drop-test-2026-09-25.md) · [Freeboard model STEP check](../engineering/buoy-structural/buoy-mass-displacement-and-freeboard-model.md#how-to-update-this-document) |
| 2026-09-28 | mechanical | Chassis print orientation | John worked through the chassis orientation trade-off with Claude. Upright puts the axial mooring load across layers and relies on interlayer bonding, weakest at the heat-set inserts. On its side keeps the load along the beads but ruins the O-ring faces. Two lengthwise halves print cleanly but put seams through every seal. Upright was chosen because the chassis must seal; the plan is to carry the axial load in stainless, not the plastic | [print-settings.md § Chassis print orientation](../engineering/buoy-structural/print-settings.md#chassis-print-orientation--2026-09-28) |
| 2026-09-28 | mechanical | Electronics housing seal layout | The inward top collar (clamp v2) left a Ø3.10 in opening, too small for a pre-assembled harness. Tried the same face seal inside a Ø114 mm body (the flange grows to ~Ø155 mm and overhangs the chassis), then an outward flange resting on the chassis top (Ø4.00 in bore, flange flush at Ø5.75 in). The flange also closes the chassis. Imperial redo on the AS568 -2xx series | [electronics-housing README](../../mechanical/cad/electronics-housing/README.md#flange-style-housing-first-pass-sizing-2026-09-28-not-yet-in-cad) |
| 2026-10-06 | mechanical | Buoy — new bottom sections printed, first glued assembly | John printed new bottom sections and assembled everything built so far (wedges, chassis, bottom caps). Inside seams glued with Gorilla Glue; marine epoxy goes on the outside once it cures. Taped in place while curing. Print versions, cure time and epoxy product not yet recorded. 18 photos: [record](../../mechanical/test/buoy-assembly-2026-10-06.md) |
| 2026-10-06 | mechanical | Electronics housing — larger flange housing on the chassis lip | John updated the housing: the static O-ring face seal now goes over the chassis lip so the flange sits on top of the chassis; the whole housing is larger; the lid has a curved cable-penetration interface with room for cable glands, angled so cables run to the side and leave vertical room for a possible solar panel. Drawing in progress; dimensions not yet recorded. Detail: [electronics-housing README](../../mechanical/cad/electronics-housing/README.md#larger-flange-housing-on-the-chassis-lip--2026-10-06-cad-in-progress-step-and-drawing-not-yet-in-repo) |
| 2026-10-06 | mechanical | Sensor pod face-seal coupon (RR-12) — first test with a purchased O-ring | 24 hr submerged in salt water, no grease, torque unrecorded: interior **slightly damp**, not flooded — misses the dry benchmark. John saw the faces touch at each of the 3 bolts but the flat cap **flex between bolts**, opening a gap there and cutting the ring's compression. Learned: the leak is joint stiffness (bolt count and cap rigidity), not the ring or groove depth. Not yet tried: more bolts, a thicker or ribbed cap. Full write-up: [record](../../mechanical/test/sensor-housing-oring-coupon-2026-10-01.md) |
| 2026-09-29 | mechanical | Capsize recovery → ballast arm | The STEP-geometry GZ curve showed the buoy stable inverted. Tried: smaller caps (no fix), lead in the chassis floor (8 kg only reaches ~120°), mooring pull at the keel (same problem, too short a lever), deep lead (works; lead × depth ≈ 60 kg·in). Chose 24 in, then 1.5 in caps with the ballast. Arm: PVC and printed PETG ruled out by root torque → 316 pipe. Joint: flange → bulkhead fitting → tie-rod clamp → slip-on rail mount + backing plate (chosen); generative bracket dropped | [Stability Analysis §12](../engineering/buoy-structural/stability-analysis.md#12-large-angle-stability-capsize-and-self-righting-ballast--2026-09-29), [Ballast Arm and Mount](../engineering/buoy-structural/ballast-arm-and-mount.md), [calculator](../../mechanical/simulations/buoy-stability/README.md) |
| 2026-09-25 | mechanical | Structural FEA — v5 re-check | Five Fusion runs at the v5 loads: LC5 wave+current (seam and near-face directions), LC8 5 m hydrostatic, LC9 snap at the ring, and ring buckling. All pass. The lowest real buoy SF is ~3.5 (PETG) at the middle of each unfoamed thin wedge wall under LC8. The ring buckles at load factor 1.87 unfoamed, which drops to about the 5 m test spec after an imperfection knock-down, so **foam fill is structurally required for the pressure test**. LC7's moment was mis-entered (42 N·mm) and closed by hand. The runs used stock ABS, so SFs were re-based to PETG. No impact case was run, so SCO-71 stays open. | [FEA results § v5 re-check](../../mechanical/test/fea-mooring-load-cases.md#results--v5-re-check-2026-09-25) |
| 2026-09-25 | mechanical | Floatation, wedge bottom — slicer weigh-in | The lean v5 wedge bottom sliced at 4 walls / 0.18 mm / 15% gyroid comes to **207.06 g**, heavier than the v4 part's 181.21 g despite the lean re-model. The settings, not the geometry, set the mass. Carried into every buoyancy calculation: nominal 7.59 → 7.75 kg, reserve 212 → 210 N (3.77×), draft 2.50 → 2.53 in, GM 9.73 → 9.56 in. No conclusion changes. The foam cavity is still the v4 figure. | [Freeboard model](../engineering/buoy-structural/buoy-mass-displacement-and-freeboard-model.md) · [SCO-111](https://linear.app/scout1/issue/SCO-111) |
| 2026-09-21 | mechanical | Full-buoy assembly, mooring bracket, cable routing | John attached the mooring bracket (`3076T33` stand-in ring) to the chassis bottom, assembled all the current parts into one Fusion model, and modeled a first candidate cable route: from the top-cap port, over the rim, down the outside of the float, along the underside, then down the line to the sensor string. Same day, the bracket mounting was decided as through-bolts, nuts and an internal backing plate (see the [decision log](decision-log.md)). The bolt pattern and backing-plate dimensions are in [facts.md](facts.md). The cable route is a concept, not a decision. Still open: whether an external run survives abrasion and snagging, where it's clamped, and how it clears the ring and mooring line. The render has no dimensions, so it doesn't confirm fit | [render](../../assets/diagrams/buoy-assembly-cable-routing-2026-09-21.png), [journal](journal/2026-09-21.md) |
| 2026-09-13 | mechanical | Sensor pod dry-chamber body + lid — first print off today's numbers | Same day as the packing analysis, wall-thickness check, and top-cap O-ring resize (all logged earlier the same day), John modeled the dry-chamber body and lid in Onshape and started a print — flood chamber not yet modeled. Chain of reasoning, in order: (1) epoxy-vs-O-ring question on the sensor-lead penetration → (2) exposed that the chamber had never been sized against real SEN0189 hardware → formal packing analysis (probe mounting ears govern, ≥Ø52 mm, not the adapter board) → (3) a real chamber needs a real wall → closed-form buckling check, 2.0 mm walls, `SF`≈4.7 → (4) growing the chamber outgrew the old top-cap flange → O-ring resized, AS568-137→AS568-142, groove re-derived against Parker/Apple Rubber squeeze standards → (5) confirmed the alignment spigot visible in the renders is intentional, with axial-clearance and diametral-clearance conditions → (6) modeled and printed. **First real weight: ~60 g** (body + lid). Renders shared in chat, not yet saved as files in the repo. Doesn't yet confirm exact dimensions against the recommendation (no dimension callouts on a shaded render), the mounting-ear layout, or anything wet-tested | [sensor-housing/README.md § Dry-chamber body + lid](../../mechanical/cad/sensor-housing/README.md#dry-chamber-body--lid-modeled-and-printing--2026-09-13) |
| 2026-09-13 | mechanical | Sensor pod — first formal dry/flood chamber packing analysis | Pulled the SEN0189's own manufacturer drawings — the adapter board datasheet (already on file) plus a probe-body mechanical drawing fetched fresh from DFRobot's official wiki (`Probe_Dimension.png`, now saved to `hardware/datasheets/`) — and computed real chamber sizing for the first time (previously "TBD" in CAD). Result: the probe's **mounting ears** (44 mm diagonal span), not the adapter board, govern the dry chamber's minimum diameter at ≥Ø52 mm — bigger than the ~Ø31.5 mm bore already committed in the 2026-08-29 face-seal remodel, so the current CAD is undersized. Also sized the probe-shaft penetration (Ø24 mm) and flood chamber (≥Ø24×30mm). **Caught and fixed a real cross-document contradiction in the process**: the [Electronics Housing Packing Budget](../engineering/electronics-housing-packing-budget.md) (2026-08-25) had wrongly included this same SEN0189 adapter board as occupying volume in the *main* housing — silently disagreeing with the sensor-pod README's own description the whole time. Confirmed with John the board lives in the pod; recomputed that document's three packing methods without it (Method 3's bare-minimum length dropped 68→63mm, volume 0.368→0.341L) | [Sensor Pod Packing Budget](../engineering/sensor-pod-packing-budget.md), [sensor-housing/README.md](../../mechanical/cad/sensor-housing/README.md#formal-dryflood-chamber-packing-analysis-2026-09-13) |
| 2026-09-10 | mechanical | Lean wedge bottom (v5) | First wedge bottom printed off the v4-era geometry was on track to waste far more filament than a non-structural impact cap needs. John stopped it, re-modelled a **lean** version (shallow 60° tray — cavity floor out to ~R6.13/R6.25 in, walls 0.120 in outer / 0.077 in sides, floor ~0.114 in, R9.000 in outer unchanged), added **registration tabs on the top rim** so the wedge shell seats firmly over it, and set it printing (printing OK as of the entry). Drawing + STEP export committed; **a re-slice for weight and print-settings re-spec still owed** — the v4 wedge-bottom mass (181.21 g) / cavity (0.452 L) still stand in the mass, freeboard, stability, and impact docs until the slice lands | [floatation/README.md § Lean wedge bottom (v5)](../../mechanical/cad/floatation/README.md#lean-wedge-bottom-v5--2026-09-10) |
| 2026-09-10 | analytics | Public site — dramatic pass (photographic hero + scroll motion) | Rebuilt the site's first impression and added restrained motion across all pages. Home now opens on a **full-viewport photographic hero** (the reef photo is the stage, type over it, hero pulled up under the sticky header, header floats transparent until you scroll off it); inner pages open on oversized display type. Sections fade in on scroll — a plain 400ms opacity fade, no travel and no stagger, after three passes (26px/900ms/350ms → 14px/520ms/180ms → none); distance and stagger were what made it read as an effect rather than the page settling. The hero parallaxes. **This reverses the design system's own rule that "motion is never scroll-dependent"** — earned by three independent fail-open guards (hiding CSS gated on a class only an inline head script sets; a 4s watchdog if `reveal.js` never runs; `prefers-reduced-motion` pins `.reveal` visible), plus `@supports` gating on scroll timelines and transform/opacity-only animation. **Deliberately cut after review:** the hero figcaption, the signal-name strip, the scroll cue, the on-image photographer credit (moved to the footer), a reading-progress bar, and a tinted gradient wash on the inner pages — all competed with the photograph or the copy rather than adding to them. Three things worth carrying forward: (1) **`.hero-figure` is not hero-only** — Science reuses it for the bleaching photo, and redefining it absolutely-positioned tore that figure out of flow; caught by diffing rendered geometry against the pre-change build, invisible to any HTML-level check. (2) **Contrast over a photo must be measured on glyph boxes, not block boxes** — the hero type is centred, so block-box sampling read far too dark; measured properly the first scrim failed AA on three elements (3.06/4.08/4.48) and the shipped one measures 5.21–9.63. (3) **A load-time animation must not outlast the navigation transition that precedes it.** The hero photograph settled over 1900ms while the cross-document view transition is 400ms, and the browser shows a frozen snapshot for that window — so the live DOM took over 21% through the zoom and the image appeared to snap into place on every nav click. The photograph is now static at a fixed scale(1.06) and the hero type lands at 630ms instead of 1520ms. Verified with a before/after content inventory across all 8 pages plus a layout audit at 320/375/768/1024/1440 | [live-dashboard.md § The dramatic pass](../engineering/live-dashboard.md#the-dramatic-pass-a-photographic-hero-and-scroll-driven-motion) |
| 2026-09-09 | mechanical | v5 structural analyses — stability, ring buckling, impact, v5 load delta | Worked the four owed closed-form mechanical analyses off the v5 geometry + mass model. **Stability ([SCO-80](https://linear.app/scout1/issue/SCO-80)):** `GM` ≈ 9.7 in (≈10× a typical target — very stiff), roll period ~0.6 s (no resonance vs the 6 s wave, but snappy), one-wedge-lost ~3° list, and the LC7 overturning moment (~42 N·m at v5) exceeds `W·GM` (~18 N·m) so the buoy heels into the flow under peak load — sustained current heel ~2°, the transient peak deferred to a coupled mooring analysis + [SCO-82](https://linear.app/scout1/issue/SCO-82) tilt test. **Ring buckling:** bare v5 wall fails external-pressure buckling (`SF` ≈ 0.2–0.7), foam-backed ≈ 3–5 — "foam before submersion" now quantified and hard. **Impact ([SCO-71](https://linear.app/scout1/issue/SCO-71)):** drift contact does no damage; a >1.5–2 m/s strike cracks a wedge shell, accepted (foam → no flood, ring → no collapse, field-replaceable). **v5 load delta:** every LC1–LC9 load is 10–30% lower at v5 than v4 (LC8 unchanged), so the v4 FEA bounds v5 for load adequacy — no urgent full re-run; the thin-wall wedge stress + ring buckling + pad-eye still need FEA. All four docs cross-linked from [`buoy-structural/README.md`](../engineering/buoy-structural/README.md) | [Stability Analysis](../engineering/buoy-structural/stability-analysis.md), [Impact Analysis](../engineering/buoy-structural/impact-survivability-analysis.md), [Ring-buckling check](../../mechanical/test/wedge-ring-buckling-check-2026-09-09.md), [Force Budget § v5 reassessment](../engineering/buoy-structural/force-budget.md#v5-geometry-reassessment-2026-09-09) |
| 2026-09-09 | mechanical | Whole-buoy mass / freeboard model — v5 rebuild | Re-solved the whole-buoy mass, displacement, and freeboard model on the **v5 geometry** (wedge 8.0 → 5.5 in, chassis 11.0 → 8.5 in, wedge walls 0.250 → 0.095/0.063 in, R9.000 unchanged) after [SCO-110](https://linear.app/scout1/issue/SCO-110). Method unchanged from the 2026-08-29 v4 build — same formulas, same 0.372 kg appendage credit, same piecewise `V_disp(T)` — only the geometry inputs changed, so the check was one careful pass + **one independent agent re-deriving every headline number** (matched to <0.5%), not the full multi-agent treatment. **Result: nominal mass 8.40 → ~7.59 kg, max buoyant force 391 → 286 N, net reserve 309 → ~212 N (4.75× → 3.84×), draft 2.69 → 2.50 in, freeboard to the wedge top 7.31 → ~5.0 in.** Still substantially over-floated (~9% of the now-5.5-in float section wetted) — conclusion unchanged, margin trimmed as the SCO-110 decision intended. ⚠️ v5 shell masses (wedge ~240 g, chassis ~600 g) are **geometric estimates** — no re-slice exists yet. v4 numbers preserved verbatim in the model doc §14 | [Buoy Mass, Displacement, and Freeboard Model](../engineering/buoy-structural/buoy-mass-displacement-and-freeboard-model.md), [Mass and Buoyancy Budget §12](../engineering/buoy-structural/mass-and-buoyancy-budget.md#12-v5-revision--sco-110-resize--thin-walls), [SCO-74](https://linear.app/scout1/issue/SCO-74) |
| 2026-09-08 | mechanical | Flotation wedge — v5 STEP exported + compliant web | John exported and committed the v5 wedge STEP ([`chassis-floatation-bolted-v5-wedge.step`](../../mechanical/cad/floatation/chassis-floatation-bolted-v5-wedge.step)). Geometry read from the STEP confirms the SCO-110 resize — **height 203.2 → 139.7 mm (8.00 → 5.50 in)**, outer radius unchanged at R9.000 in, ~2× the B-rep face/circle count of v4 from the added internal web + lightening holes. John's narration: the web that closed the open cavity on 2026-09-07 is now also a **perforated compliant panel spanning between the bolt flanges** — the holes let it flex to seat around the chassis and give **service access to the chassis** without a rigid interference fit, on top of the earlier DFM/structural role. Wall thicknesses (0.095/0.063 in) and the ~0.69 in bolt flange are per narration + the 2026-09-07 check — **a dimensioned PDF is still needed to verify them**; v5 chassis + caps not yet re-exported so `current/` still holds v4 | [floatation/README.md → STEP exported](../../mechanical/cad/floatation/README.md#step-exported--2026-09-08), [SCO-110](https://linear.app/scout1/issue/SCO-110) |
| 2026-09-08 | mechanical | Turbidity sensor housing — cap + body re-confirmed, flood chamber re-spec | John re-exported and sent the sealed cap + no-port body; both are **byte-identical geometry** (normalised diff) to the committed `sensor-housing-sealed-cap-v2.step` / `sensor-housing-body-face-seal.step`, so no new files — this confirms the v2 cap (Ø31.496 mm spigot, previously flagged as "not narrated") and the face-seal body as his current parts. **Flood chamber deliberately excluded — being re-specced.** Separately, John opened a task to examine Isabella's actual Rev A turbidity sensor and adapt the flood chamber + body around it rather than the generic SEN0189 assumption | [sensor-housing/README.md](../../mechanical/cad/sensor-housing/README.md#flood-chamber--being-re-specced-2026-09-08), [SCO-91](https://linear.app/scout1/issue/SCO-91) |
| 2026-09-07 | mechanical | Flotation wedge — thin walls + DFM bracing web (v5) | After the 5.5-in resize ([SCO-110](https://linear.app/scout1/issue/SCO-110)), John thinned the wedge shell over several slicing passes to **outer wall 0.095 in / side walls 0.063 in** (both now fully-dense perimeter shells, no infill core) — *"light and not to waste filament."* The thin open walls **flexed during printing** under toolhead forces and **broke first-layer bed adhesion**; the fix was an **internal bracing web with lightening cutouts** connecting the previously-open walls — a DFM change that also does structural work (halves every panel span, adds a shear web), so **the DFM fix and the structural fix are one change** (highlight). Closed-form structural check: **outer wall 0.095 in accepted as the floor** (SF 7.3 on yield under 50.3 kPa hydrostatic); **side walls 0.063 in accepted** — John confirmed the six wedges are **exactly 60°**, the **radial seams epoxied**, and **foam poured after the wedges are bolted into the ring**, making them an **epoxied closed monocoque ring**: each radial wall sees no through-thickness service pressure, the bonded 3.2 mm seam is a compression-ring path + composite stringer, and foam-fill pressure is reacted by the bonded neighbour. **Key consequence: the epoxied wedge ring is the primary structure and the foam is required backing against local/asymmetric loads** (a single bare panel is marginal on external-pressure buckling; the bonded ring is much stiffer but needs an assembly-level buckling FEA to confirm). Foam must be in before any submersion. Bolt loads stay on the ~0.69 in inner flange. Impact ([SCO-71](https://linear.app/scout1/issue/SCO-71)) is now more wall-thickness sensitive. v5 STEP not yet exported; mass/freeboard recompute is [SCO-110](https://linear.app/scout1/issue/SCO-110) | [`mechanical/test/wedge-wall-thickness-structural-check-2026-09-07.md`](../../mechanical/test/wedge-wall-thickness-structural-check-2026-09-07.md), [floatation/README.md](../../mechanical/cad/floatation/README.md#thin-wall--dfm-bracing-web-iteration-v5--2026-09-07) |
| 2026-09-02 | mechanical | Electronics housing (sealing clamp) | New **clamp + lid pair** ('Clamp 2 AS568-043') carrying a static face seal: 6 fasteners moved **outside** the O-ring boundary (Ø104.14 mm bolt circle vs. a Ø91.69 mm groove OD), the groove dimensioned to a standard **AS568-043** ring, and the seal faces reinforced to bottom out land-to-land so squeeze comes from geometry rather than bolt torque. Checked the groove against the ring: **22.9 % squeeze, 75 % gland fill** — both inside standard static-face-seal practice, so 'aligned dimensions with standard o ring' holds on the two numbers that matter; the ring's *diameter* fit against the Ø86.87 mm groove ID is the one still unverified. This is the same remodel already applied to the sensor pod on 2026-08-29, and it closes the design panel review's lid-seal finding on [SCO-68](https://linear.app/scout1/issue/SCO-68). Printed and found to have slight O-ring tolerance trouble — reprint pending, offending dimension not yet recorded. The lid carries **engraved identifying language** (four lines, 1.27 mm deep); the STEP stores it as glyph geometry, not text, so the wording needs confirming from John. Two gaps found by inspection rather than reported: the lid as exported has **no clearance holes** for the 6-bolt pattern, and the older end-cap-into-cylinder concept in the same folder is incompatible with this one — which is baseline is undeclared. Separately, the sensor pod's **sealed cap spigot was quietly reduced Ø31.75 → Ø31.496 mm** (the only diff in that export); the pod body re-export is geometrically identical to what was already committed | [electronics-housing/README.md](../../mechanical/cad/electronics-housing/README.md#static-face-seal-clamp--2026-09-02), [sensor-housing/README.md](../../mechanical/cad/sensor-housing/README.md#sealed-cap-spigot-tolerance-tweak--2026-09-02) |
| 2026-08-29 | mechanical | FEA LC3–LC9 + service run — **buoy structure validated** | Ran the remaining framework load cases in Fusion (custom PETG profile, `3076T33` steel tie-down ring stand-in). **The buoy structure passes every case** — LC3 (current, min SF 1450), LC4 (wave, 70), LC5 (wave+current 440 N, 30 face / 65 edge), service (290), LC8 (hydrostatic/5 m, 10). LC6 (combined) and LC9 (snap) show min SF 1.5–1.7 with 40–50 MPa contact pressure — **John examined the reports and confirmed these are contact-singularity artifacts at the `3076T33` stand-in ring's bonded interface** (coarse mesh, no refinement, generic-steel placeholder part), not the buoy PETG (which is nowhere near yield — if it were the limiter LC9 min SF would be ~0.25). **Judgement: sufficient for now, the buoy structure is validated against LC1–LC9.** Deferred, not dropped: the final 316 pad-eye + its real mounted interface (through-bolt/inserts into the 76 mm solid section) get a dedicated re-run with LC7's 70 N·m moment and LC6 at the correct vector — panel Action A1, before deployment. Also open: PETG density 1.06→1.27, explicit SF target. Reports committed with embedded plots stripped (repo weight) | [`mechanical/test/fea-mooring-load-cases.md`](../../mechanical/test/fea-mooring-load-cases.md) |
| 2026-08-29 | mechanical | Turbidity sensor housing — face-seal remodel | Reworked the body↔cap joint into a proper **static face seal**: the AS568-137 O-ring now sits in a single continuous face groove with the mating PETG faces designed to **fully touch (hard stop)** at full assembly, so the squeeze % is set by the faces bottoming out rather than by fastener torque. Separately, the **bolt flanges were reinforced** so bolt-flange bowing/bending between the 3 bolts no longer locally lifts the groove face and drops the O-ring compression between the bolts — the stiffer flange keeps the compression uniform around the circumference. New STEP files `sensor-housing-body-face-seal.step` + `sensor-housing-sealed-cap.step` supersede the prior `-current` body/cap. Open: confirm the face-groove width/depth against an AS568-137 face-seal table (the CAD torus reads a ~3.18 mm minor radius vs. the 2.62 mm ring CS); submersion re-test of the remodelled housing; heat-set insert sizing. A face-seal / flange-bowing FEA (custom PETG profile) is the natural next study after the buoy LC3–LC9 runs | [`mechanical/cad/sensor-housing/README.md`](../../mechanical/cad/sensor-housing/README.md#face-seal-remodel--2026-08-29) |
| 2026-08-29 | mechanical | FEA LC2 run + custom PETG profile | First run of the corrected LC1–LC9 framework loads: **LC2** (322 N taut-line vertical uplift) on the mooring attachment, in Fusion, with a **custom PETG material profile** John built (E 2240 MPa, ν 0.38, yield 35 MPa, UTS 45 MPa) and a McMaster `3076T33` steel tie-down ring as the attachment stand-in. **Min SF 7.53, 0.012 mm peak displacement — comfortable pass**; peak von Mises ~27 MPa sits in the steel ring, the PETG stays well under its 35 MPa yield. Flagged, not reconciled: (a) the PETG profile density is **1.06 g/cm³**, carried over from the 2026-08-17 ABS profile — PETG is ~1.27, which is what the mass budget uses; immaterial for a static case but a real inconsistency; (b) Fusion's Guided-Results banner said "expected to bend permanently or break" against a min SF of 7.53 — a Safety-Factor-target setting artifact, not a real result. LC3–LC9 are John's top priority to run and upload — **LC9 (the ~810 N mooring snap) is the governing case**; LC2 alone does not sign off the attachment | [`mechanical/test/fea-mooring-lc2-vertical-uplift-2026-08-29.md`](../../mechanical/test/fea-mooring-lc2-vertical-uplift-2026-08-29.md), [`fea-mooring-load-cases.md`](../../mechanical/test/fea-mooring-load-cases.md) |
| 2026-08-29 | mechanical | Mooring attachment — pad-eye chosen (trade study) | Panel review Action A1 (the project's critical single-point failure) worked through six options against the same-day FEA loads (LC2 322 N uplift, LC6 586 N, LC9 ~810 N snap): rigid U-bolt + backing plate (prior baseline), clamped 316 cable loop through the chassis holes, bonded flanged eye, through-bolted folding pad-eye, tapped block + shoulder eye bolt, transverse cross-pin clevis. The **cable idea** was assessed in detail and rejected — its compliance benefit is real but belongs in the mooring line, and it trades a well-understood bolt/boss failure for chafe at the printed PETG hole edges (near-certain over a year without a bonded metal thimble), wire-rope bend fatigue at a tight D/d (~3–6 through 52 mm-spaced holes), and a swaged termination sealed inside the chassis where broken wires can't be inspected. Chose the **through-bolted 316 pad-eye**: 4-point load spread vs. the U-bolt's 2, fully external / inspectable / field-replaceable, standard hardware. **Cross-pin clevis kept as the strong fallback** — printed plastic takes bearing + shear far better than pull-out. Shock compliance moves to the mooring line (snubber / catenary, [ADR-0004](../decisions/0004-reef-safe-anchoring-and-mooring.md)), not the buoy penetration. Still open on [SCO-69](https://linear.app/scout1/issue/SCO-69): specific part, sizing, threaded inserts, chassis-bottom boss design, proof test | [SCO-69](https://linear.app/scout1/issue/SCO-69), [Force Budget](../engineering/buoy-structural/force-budget.md) |
| 2026-08-29 | mechanical | Whole-buoy mass / freeboard model + FEA design loads | Extended the printed-shell sub-budget to the complete deployed buoy via a verified multi-agent pass (3 independent derivations → reconcile → 2 adversarial math checks → 2 auditors): as-deployed mass **~8.40 kg nominal** (Tier III — battery, solar, stem, pod, mooring hardware — still `[A]` on SCO-70), max buoyant force **391 N**, net reserve **~309 N**. Foam mandated to fill all six wedge modules (27.8 L, 0.89 kg at 2 lb/ft³). The freeboard solve (floating equilibrium, piecewise `V_disp(T)`, submerged appendages as `weight − displacement`) gives **nominal draft 2.69 in, 7.31 in freeboard to the wedge top** — the buoy is **substantially over-floated**: only ~9% of the 18-in float section wetted, ~4.75:1 margin, +14 kg needed to reach mid-wedge draft. Design implication: the float is oversized for flotation; the real levers are less foam, fewer/smaller wedges, or low chassis ballast (which also helps CG for SCO-80). Then used this geometry + the [structural load framework](../engineering/buoy-structural/structural-load-framework.md) to compute the Fusion FEA load set at a **proposed** (not yet signed-off) environmental design set: LC2 uplift +322 N, LC5 aligned wave+current ~440 N, wind ~50 N high, LC6 resultant 586 N @ 57°, LC7 +70 N·m, LC8 hydrostatic 50.3 kPa (5 m spec), LC9 snap ~810 N. Linear-wave-theory validity flagged (Ursell ≈ 98). The prior 300 N side-load FEA (SF 25.4) is ~1.5× under-scale vs LC5/LC6 → implied re-run SF ~16, still over-engineered | [Buoy Mass, Displacement, and Freeboard Model](../engineering/buoy-structural/buoy-mass-displacement-and-freeboard-model.md), [Force Budget](../engineering/buoy-structural/force-budget.md) |
| 2026-08-25 | mechanical | Electronics housing — first packing analysis | Pulled real component dimensions out of Isabella's Rev A datasheets (Feather M0 51×23×8mm, PKCELL battery 35×30×5mm from its drawing page, SEN0189 adapter board 38×28×10mm) rather than relying on the schematic's net-list alone, then computed three candidate cylindrical packing layouts: an axial stack (⌀65×98mm, 0.325L — smallest volume, longest tube), a single flat layer (⌀123×60mm, 0.711L — shortest tube but exceeds the existing ~4" PVC reference), and a two-zone hybrid (⌀83×68mm, 0.368L). Recommended the hybrid — nearly as volume-efficient as the axial stack, a third shorter, and fits inside the existing PVC reference with margin, so it doesn't force a mechanical-design change. Flagged two real gaps rather than papering over them: the Adafruit PID 6106 charger board's dimensions aren't in the repo (only the bare BQ25185 chip datasheet is), so its footprint is an assumed 51×25×10mm pending a caliper check; and the antenna routing (internal wire whip vs. uFL+SMA bulkhead) isn't decided, which changes the endcap design not just internal layout. Explicitly out of scope: wall thickness and pressure rating, a separate structural question | [Electronics Housing Packing Budget](../engineering/electronics-housing-packing-budget.md) |
| 2026-08-24 | mechanical | Waterproofing — first submersion test, 3 articles | Bench submersion test using a toilet-paper moisture indicator sealed inside each housing. **All three articles used 3D-printed O-rings, chosen purely because printing was faster than sourcing off-the-shelf ones for this test** — not a deliberate evaluation of the settled O-ring sourcing decision. A PLA sensor housing sealed with a TPU-printed O-ring **passed cleanly** (~30 hr submerged, paper bone-dry); a PETG print of the same housing at lower print quality **failed** (working hypothesis: a visibly stringy printed O-ring seated poorly — untested against the alternative explanation that it's PLA vs. PETG, since both variables differ at once); the **electronics housing failed with significant water ingress**, expected rather than surprising since the physical article had no rubber sealing washers at the bolt joints despite that being the documented spec in [`electronics-housing/README.md`](../../mechanical/cad/electronics-housing/README.md). **Flagged, not resolved:** the PLA pass is informal evidence worth noting next to the 2026-08-17 decision to use off-the-shelf O-rings, but since the test wasn't controlled for that question, it doesn't establish anything about it either way | [`mechanical/test/waterproofing-submersion-test-2026-08-24.md`](../../mechanical/test/waterproofing-submersion-test-2026-08-24.md) |
| 2026-08-24 | mechanical | Floatation weigh-in — all five parts now measured | John sliced and weighed all five current bolted-v4 parts (Chassis, Wedge, Wedge Bottom, Chassis Cap, Wedge Cap) with the real slicer/scale, retiring the 1.178× calibration factor that had covered the three still-unmeasured parts since 2026-08-21 — every part now has its own real weight. Final part weights use the slicer's Model figure only, with support material (present on the Chassis and Wedge Cap) excluded as sacrificial. Individually, every part moved substantially against its prior estimate: Wedge 474.58→325.83 g (−31%), Wedge Cap 65.4→126.86 g (+94%), Wedge Bottom 136.7→181.21 g (+33%), Chassis 410→712.82 g (+74%), Chassis Cap 134→89.79 g (−33%). **Flagged, not reconciled:** the Wedge's own two real measurements (474.58 g on 2026-08-21, 325.83 g today) disagree by ~31% with no logged settings or CAD change between them — per Standing Rule 1, this is recorded as an open discrepancy rather than picked one way silently; see [Mass and Buoyancy Budget §2](../engineering/buoy-structural/mass-and-buoyancy-budget.md#2-calibration-against-the-one-real-data-point--retired-2026-08-24). Re-ran the whole aggregate: despite every part moving individually, the whole-shell total landed at **5.494 kg / ~337.6 N (≈34.4 kgf) net reserve buoyancy — within 4 g and 0.1 N of the prior estimate**, because the wedge-family drop and the chassis-family rise happened to largely cancel out; called out in the doc as a coincidence of this data set, not a pattern to expect going forward. Also fixed a stale `m_b ≈ 4.0 kg` figure in [Force Budget](../engineering/buoy-structural/force-budget.md) that had never been updated after the 2026-08-21 recalibration bumped the real total to ~5.49 kg | [Buoy Mass and Buoyancy Budget](../engineering/buoy-structural/mass-and-buoyancy-budget.md), [`mechanical/test/print-weight-verification-2026-08-24.md`](../../mechanical/test/print-weight-verification-2026-08-24.md) |
| 2026-08-24 | analytics | Public site — three list sections become sticky splits | Replaced the card grids on Home ("What it measures"), Technology ("The subsystems") and Science ("Listening to the reef") with a shared **sticky split**: the section heading holds still in the left column while the entries scroll past it on the right. The grid was the constraint in all three — equal squares give every item identical weight and cap each description at about two lines, which is not enough for the hydrophone entry's "stored locally, never sent over the radio" caveat to land. Per-section judgement calls: Home's kickers became numbered (`Signal 01`…`04`) because four repeats of "Signal" read as noise once stacked, and its modular-payload note folded in as a fifth closing entry; Science keeps its two methodology columns as a full-width bento *below* the split, since they are a different register from the index list, with a gap deliberately wider than the ~104 px between two indices so they do not read as a seventh one. Sticky only above 880 px; below that each collapses to an ordinary stack, heading first. Deliberately no scroll-driven reveal — the site's motion rule is that content is visible on first paint. Two things learned: a `max-width` in `ch` on a heading *wrapper* resolves against the wrapper's font size, not the `h2` inside, and silently collapsed the column to a third of its width; and the browser-pass lesson from the 2026-08-16 row held again — the layouts were verified by measuring rects and screenshotting built pages, not by asserting on strings | [live-dashboard.md § The sticky split](../engineering/live-dashboard.md) |
| 2026-08-21 | mechanical | Wedge weight — first real calibration update | John sliced a single Wedge shell with the current decided print settings (3–4 walls, ~15% gyroid, PETG): **474.58 g**, a real slicer output (155.36 m filament, 11h8m print time), not a hand calculation. This supersedes the earlier ~300 g figure (2026-08-18), which predated the print-structure decision and used different/undecided settings — not a like-for-like comparison. The new figure sits much closer to the geometric model's own estimate (559 g, now only 1.18× high vs. the old 1.86× gap), which makes sense: the calculation and the slice now use the same settings. Recalibrated the Wedge Cap and Wedge Bottom's estimates off the new 1.178× factor and re-ran the whole aggregate: printed shell system revises from ~4.0 kg / ~352 N net reserve buoyancy to **~5.49 kg / ~337.5 N (≈34.4 kgf) net reserve buoyancy** — still a large margin, just not as large as the earlier estimate implied. Foam's own standalone buoyancy figure (~271 N across all six wedges, shell fully gone) is unaffected, since it depends on cavity volume, not shell weight | [Buoy Mass and Buoyancy Budget](../engineering/buoy-structural/mass-and-buoyancy-budget.md) |
| 2026-08-21 | mechanical | Mass, buoyancy & force budgets (new running docs) | John provided five dimensioned drawings (wedge, wedge cap, wedge bottom, chassis, chassis cap) for the current bolted-wedge v4 design. Extracted geometry, computed weight/displacement/buoyancy per part, and calibrated the method against the one real data point on record (300 g slicer-measured wedge weight vs. 558 g calculated — used the 1.86× gap to correct the other four parts, which have no slicer data yet). Confirmed the buoy's overall diameter is **18 in** (R9.000 in consistently across three drawings), resolving the design panel review's radius-vs-diameter ambiguity. Computed foam-fill weight and — separately — the foam's own standalone buoyancy if the shell is fully gone (~271 N net across all six wedges), a quantified answer for the panel review's "cracked wedge retains buoyancy" requirement. Whole shell system (6 wedges + chassis + chassis cap): ~4.0 kg, ~38.9 L displacement, ~352 N net reserve buoyancy before electronics/battery/mooring hardware are added. Restructured into three permanent, living reference docs per John's request — mass/buoyancy, forces, and print settings each get their own file with full math shown and a slot for real measured values as parts are sliced, rather than one static snapshot | [Buoy Mass and Buoyancy Budget](../engineering/buoy-structural/mass-and-buoyancy-budget.md), [Force Budget](../engineering/buoy-structural/force-budget.md), [Print Settings](../engineering/buoy-structural/print-settings.md) |
| 2026-08-21 | mechanical | Chassis / wedge print structure (walls, infill) | Researched FDM/PETG structural-print literature to fill a gap the [design panel review](../engineering/reviews/buoy-preliminary-design-panel-review-2026-08.md) left open — it recommended "thicker walls, ribs, modest infill" for the chassis but gave no numbers. Key finding: wall count dominates infill for FDM structural strength (2→5 wall loops ≈ +60% strength for +20% material; infill 20%→80% ≈ +25% strength for +150% material), and heat-set-insert pull-out depends on solid perimeters around the hole, not bulk infill. Landed on: wedge family unchanged (3–4 walls/~15% gyroid, panel-endorsed); chassis at 6 walls/25–30% gyroid generally and 8–10+ walls/100% local solid at the U-bolt boss; chassis cap provisionally matching the chassis. Logged as the working construction spec, explicitly provisional until [SCO-73](https://linear.app/scout1/issue/SCO-73)'s FEA loads exist to check it against | [decision-log.md](decision-log.md), [facts.md](facts.md#mechanical--deployment), [research/sources.md](research/sources.md) |
| 2026-08-21 | mechanical | Flotation / structural chassis / mooring / sealing | Ran a simulated multidisciplinary design panel review (12 reviewer personas) of the buoy's flotation, structural chassis, mooring, sealing, manufacturing, and field-reliability architecture. Panel recommendation: **proceed to detailed design, no redesign** — the six-wedge + central-chassis architecture is confirmed (8.0/10). Flagged the U-bolt/backing-plate/chassis mooring load path as the single most consequential unresolved item (rated a critical single-point failure), alongside chassis print structure (5.0/10, "incomplete rather than fundamentally poor" — 3–4 perimeters is only ~1.2–1.6 mm of shell), and a lid-seal issue: fasteners currently sit inside the O-ring boundary, turning every one into a potential leak path. 14 prioritized actions triaged against Linear: 5 folded into existing tickets with added acceptance criteria ([SCO-69](https://linear.app/scout1/issue/SCO-69) U-bolt/backing-plate load path — priority raised to High; [SCO-73](https://linear.app/scout1/issue/SCO-73) fatigue/cyclic-loading criterion; [SCO-68](https://linear.app/scout1/issue/SCO-68) O-ring-boundary fastener fix + gland sizing; [SCO-53](https://linear.app/scout1/issue/SCO-53) and [SCO-48](https://linear.app/scout1/issue/SCO-48) cross-referenced via comment, unchanged), 9 filed as new issues ([SCO-74](https://linear.app/scout1/issue/SCO-74)–[SCO-82](https://linear.app/scout1/issue/SCO-82): mass/displacement budget, chassis print structure, stability/CG-CB, foam-fill trials, buoyancy-under-failure verification, fastener strategy, coating durability, biofouling/field-handling features, integrated proof tests) | [Buoy Preliminary Design Panel Review](../engineering/reviews/buoy-preliminary-design-panel-review-2026-08.md) |
| 2026-08-20 | mechanical | Structural loads (FEA) | Reviewed a ChatGPT-drafted FEA load-calculation framework for accuracy before running any simulations. Core physics (buoyancy, quadratic drag, linear wave theory, Morison equation) checked out against DNV-RP-C205/USACE CEM conventions. Found and corrected one real contradiction — the draft's static mooring baseline assumed a taut line, but ADR-0004's swing-radius requirement means SCOUT's mooring is slack/catenary, so the true calm-water tension is far below full net buoyancy; split into a proper catenary baseline (blocked on scope/line-weight data) and a relabeled taut-line case kept as a conservative upper bound. Also fixed: wave drag and inertia peak at different phases and need a phase sweep, not a same-instant sum; the overturning moment needs per-component lever arms (wind acts high, water drag acts through the draft) instead of one shared value; coefficient selection needs Reynolds/Keulegan-Carpenter numbers, not a generic cylinder table. Corrected framework + formalized equations, each tagged by provenance (measured/chosen/literature/exact/wave-theory/assumption) for the final report | [Buoy Structural Load Framework](../engineering/buoy-structural/structural-load-framework.md) |
| 2026-08-20 | mechanical | Floatation (wedge design) | Two new parts added to the bolted wedge assembly: a **chassis cap** (covers the chassis cylinder, extends slightly over each wedge top — OD vs. chassis not yet decided) and a **wedge cap** (press-fit + epoxy into the wedge, sealing the foam cavity). Planned sequence: epoxy the wedge cap in, then inject foam — the small gap under the chassis cap lets expanding foam overflow there for a clean trim, the same role flash plays in injection molding. Two open questions: cable-exit routing (channel down one wedge vs. a direct through-hole) and the solar mount's attachment to the chassis cap. This is a first pass at the [SCO-53](https://linear.app/scout1/issue/SCO-53) cable-gland cap revision, not yet meeting its acceptance criteria | [mechanical/cad/floatation/README.md#chassis-cap--wedge-cap-added--2026-08-20](../../mechanical/cad/floatation/README.md#chassis-cap--wedge-cap-added--2026-08-20) |
| 2026-08-18 | mechanical | Mooring / tether | New criterion from John Ryan: the mooring/sensor-string line should **foul a boat propeller rather than get cut by it** — a cut line loses the buoy adrift, a fouled prop just stops the boat. ADR-0004 already left final line material/diameter as a routine sizing decision (not architectural); this adds a concrete requirement to weigh against its existing reef-safety and durability criteria. Not yet researched or decided | [ADR-0004](../decisions/0004-reef-safe-anchoring-and-mooring.md), [open-questions.md](research/open-questions.md), [SCO-72](https://linear.app/scout1/issue/SCO-72) |
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

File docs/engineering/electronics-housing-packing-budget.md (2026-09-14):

# Electronics Housing — Component Packing Budget

> **Summary** — First-pass geometric analysis of the Rev A electronics going inside the sealed
> electronics housing: real component dimensions pulled from Isabella's datasheets in
> [`hardware/datasheets/`](../../hardware/datasheets/), three candidate packing layouts, and the
> resulting minimum diameter/length/volume for each. **This is a packing estimate, not a
> structural or pressure-rating analysis** — wall thickness and depth rating are a separate
> question or a future pass. Feeds [`facts.md`](../hub/facts.md#build-platform-settled--see-adr-0001)'s
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

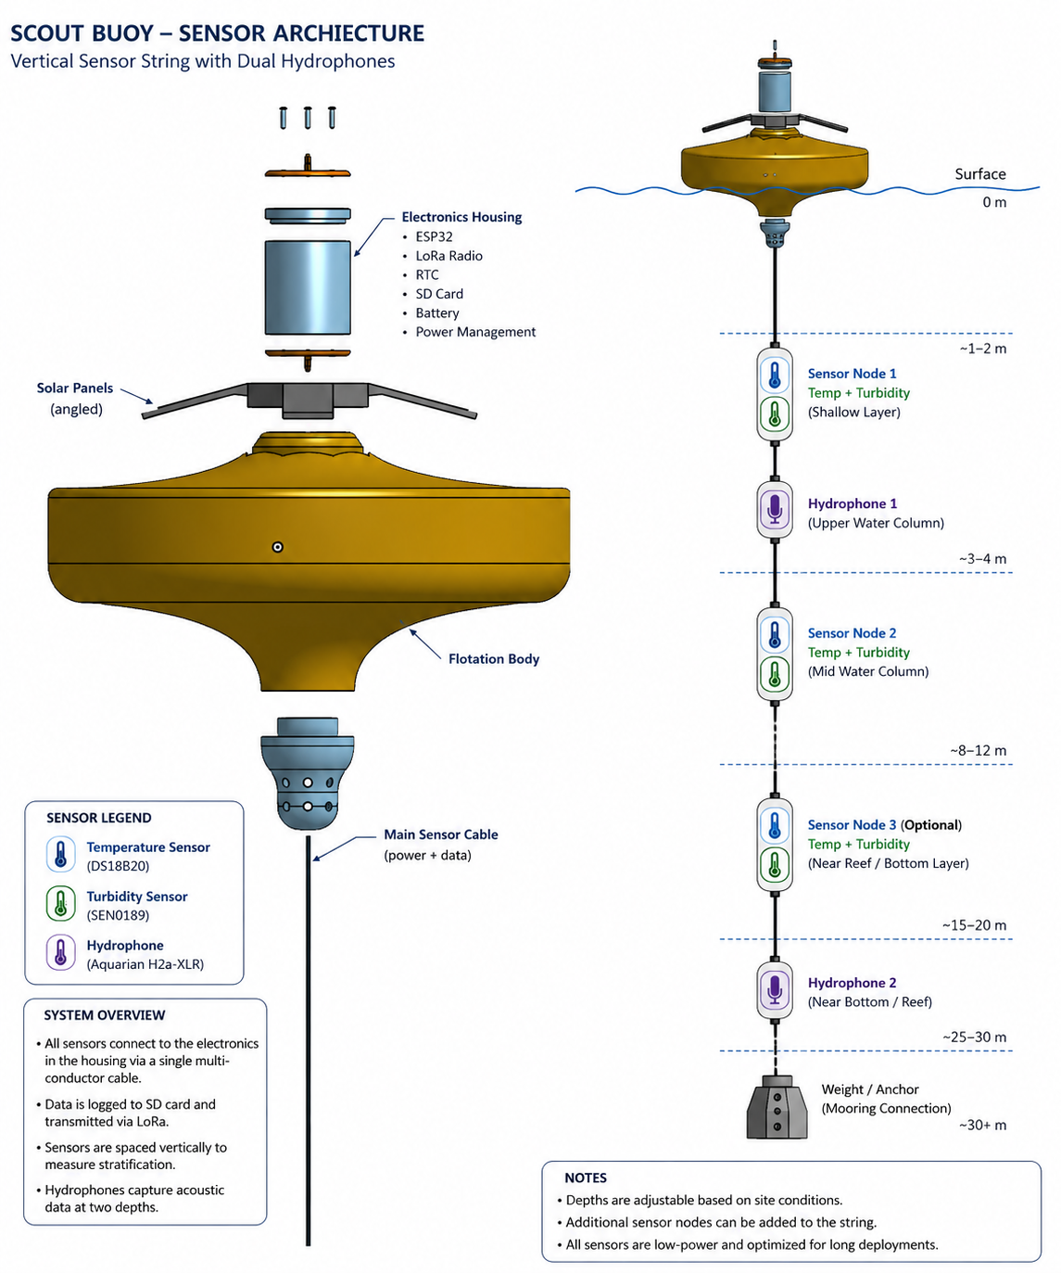
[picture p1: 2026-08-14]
assets/diagrams/sensor-string-architecture.png

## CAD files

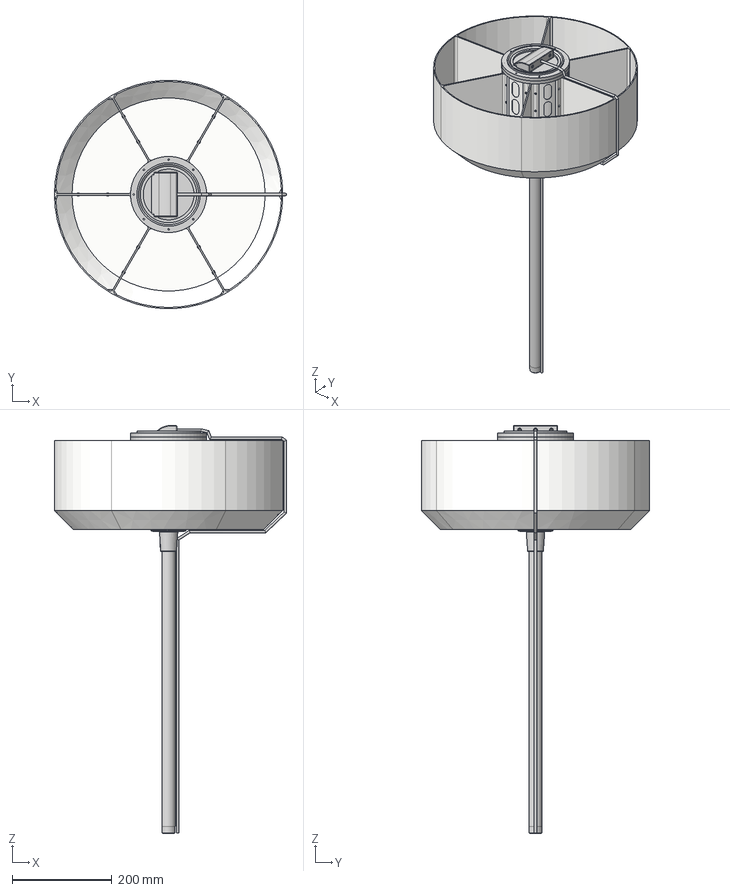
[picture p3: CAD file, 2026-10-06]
mechanical/cad/full-buoy-assembly-v7.step
464.8 x 456.4 x 816.5 mm
4816K51_NO THREADS_Standard-Wall 316-316L Stainless Steel Pipe
6040T56_Stainless Steel Slip-on Framing Fitting

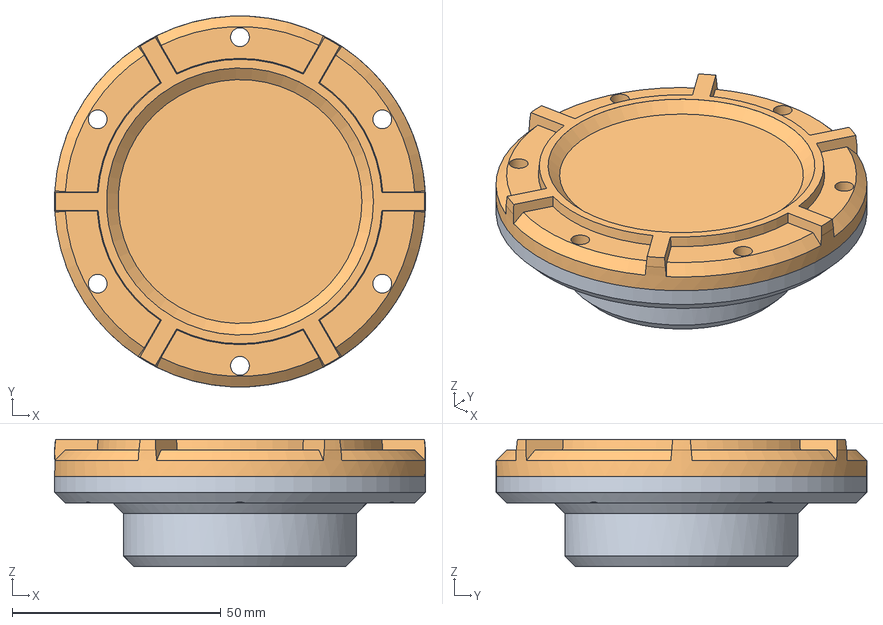
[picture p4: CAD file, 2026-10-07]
mechanical/cad/sensor-housing/sensor-housing-assembly-v9.step
88.9 x 88.9 x 30.5 mm

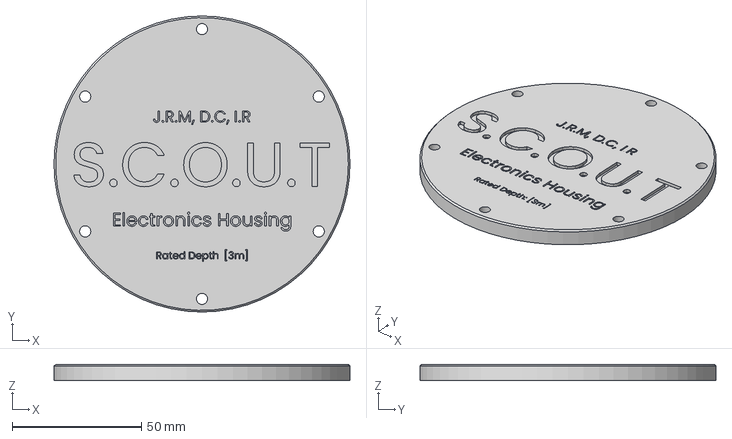
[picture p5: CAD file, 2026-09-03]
mechanical/cad/electronics-housing/electronics-housing-clamp-v2-lid.step
114.3 x 114.3 x 6.35 mm

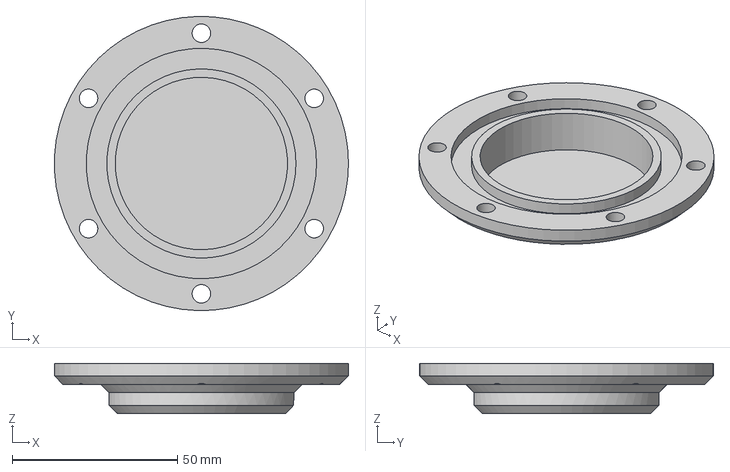
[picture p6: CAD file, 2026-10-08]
mechanical/cad/sensor-housing/sensor-housing-body-short-v1.step
88.8 x 88.9 x 15.2 mm

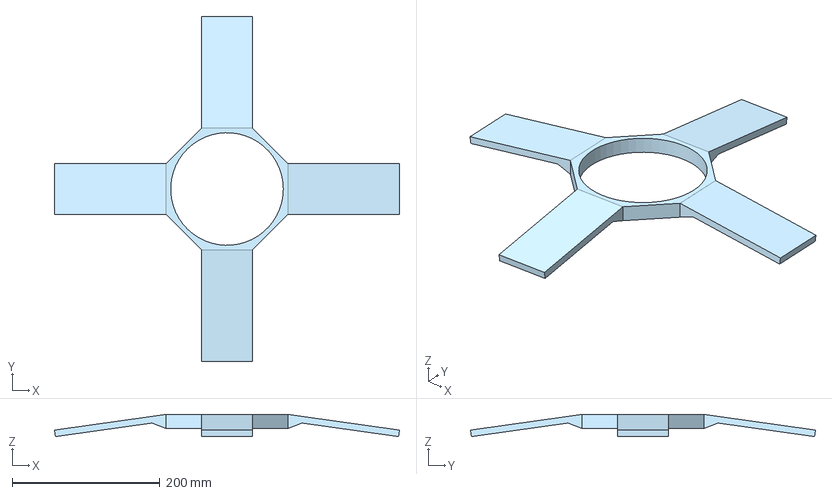
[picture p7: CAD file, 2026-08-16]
mechanical/cad/solar-mount/solar-mount.step
466.9 x 466.9 x 30.1 mm

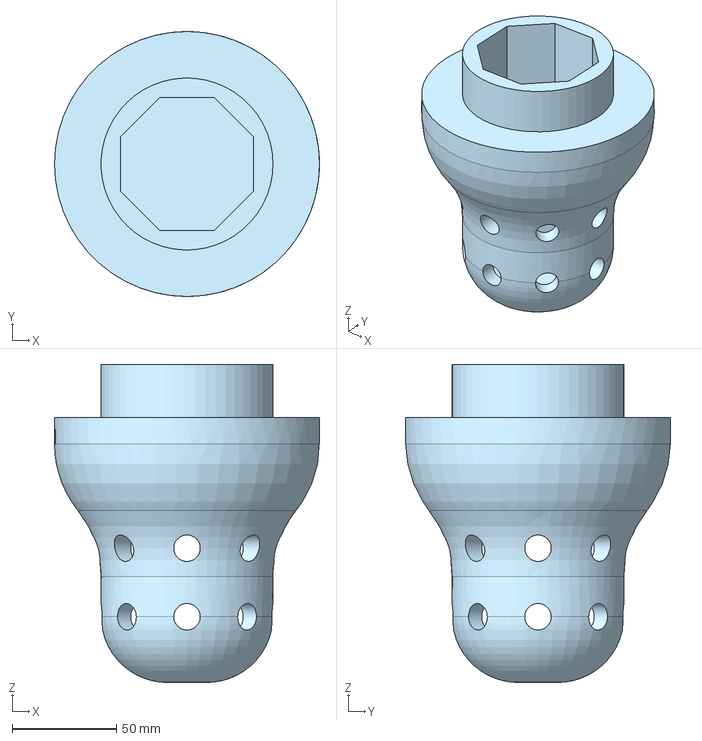
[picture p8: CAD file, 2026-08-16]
mechanical/cad/stem/stem-v2.step
127.0 x 127.0 x 152.4 mm

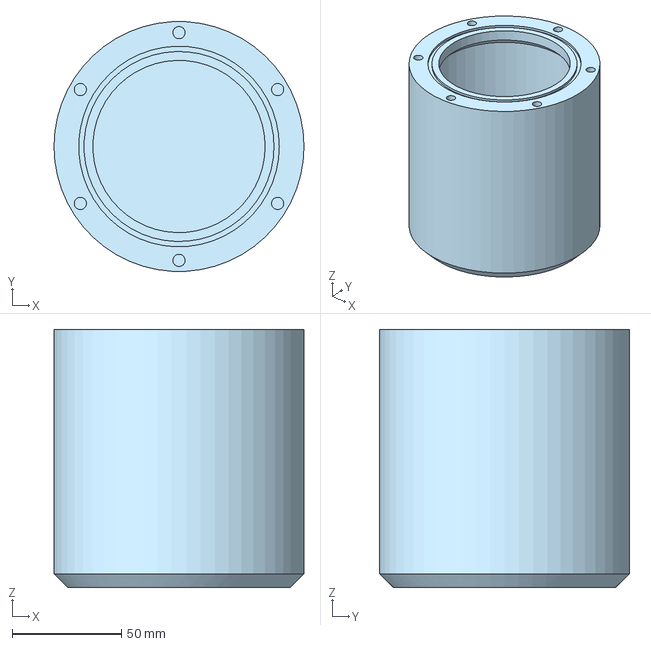
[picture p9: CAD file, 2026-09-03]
mechanical/cad/electronics-housing/electronics-housing-clamp-v2-body.step
114.3 x 114.1 x 118.1 mm

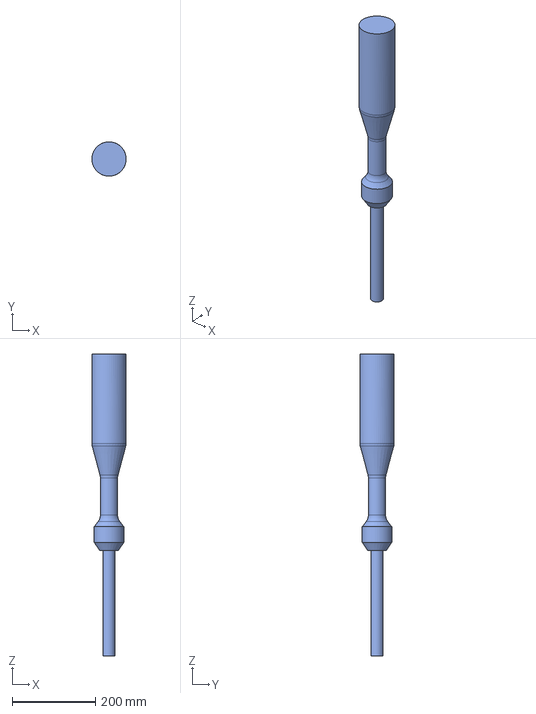
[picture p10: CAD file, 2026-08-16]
mechanical/cad/stem/stem-initial-concept.step
82.5 x 82.5 x 726.4 mm

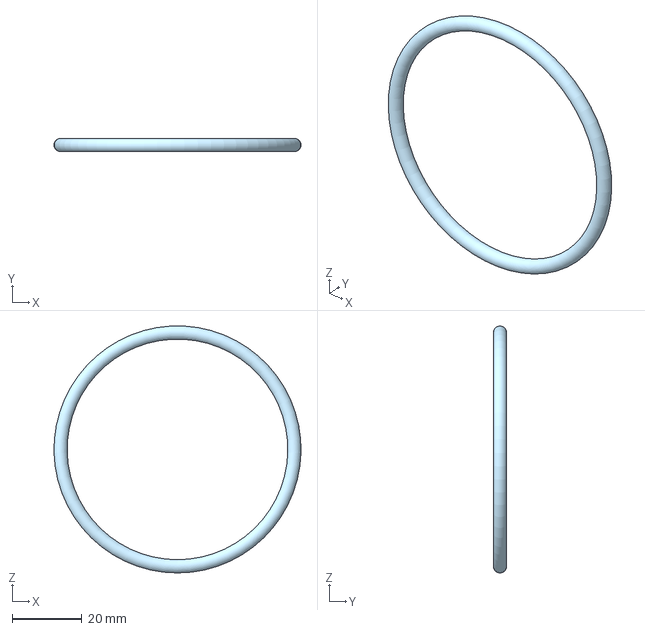
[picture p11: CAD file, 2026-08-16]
mechanical/cad/electronics-housing/electronics-housing-o-ring.step
70.8 x 3.81 x 70.8 mm

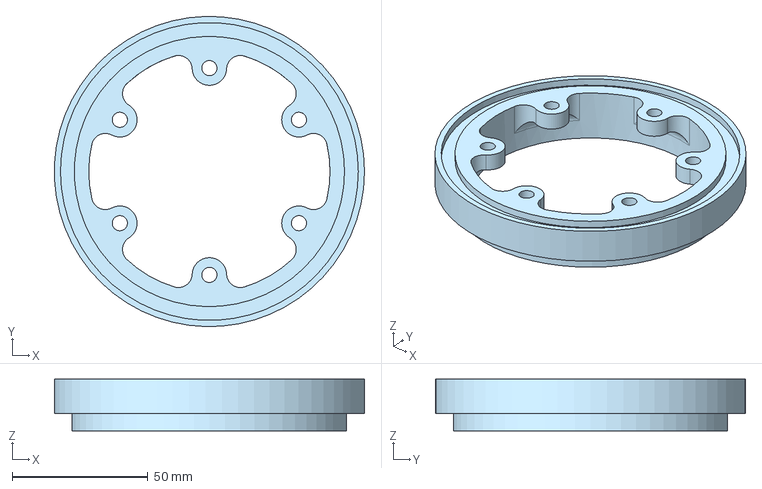
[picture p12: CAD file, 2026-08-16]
mechanical/cad/electronics-housing/electronics-housing-top-fitting.step
114.2 x 114.3 x 19.0 mm

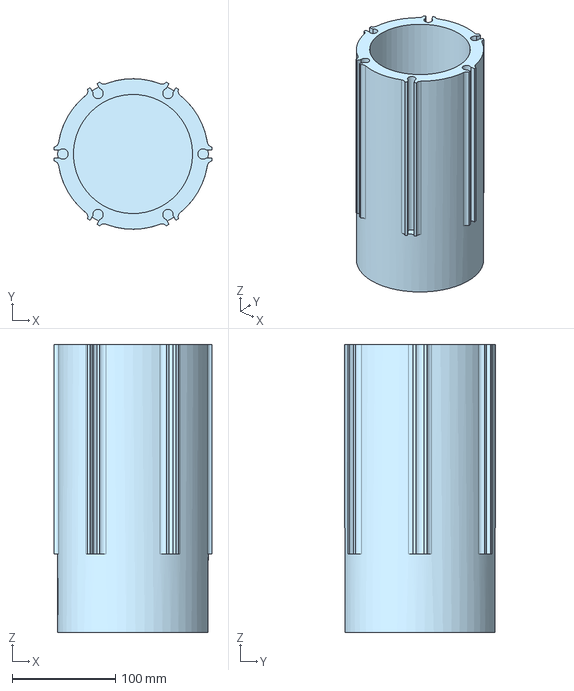
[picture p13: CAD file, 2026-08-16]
mechanical/cad/floatation/chassis-floatation-integrated-v3-part1.step
153.0 x 146.1 x 279.4 mm

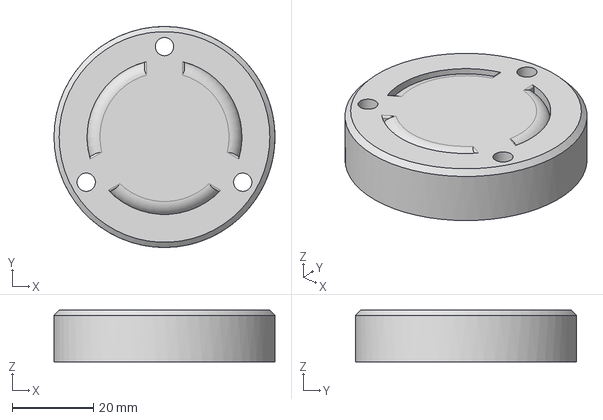
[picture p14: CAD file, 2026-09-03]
mechanical/cad/sensor-housing/sensor-housing-sealed-cap-v2.step
54.4 x 54.4 x 12.7 mm

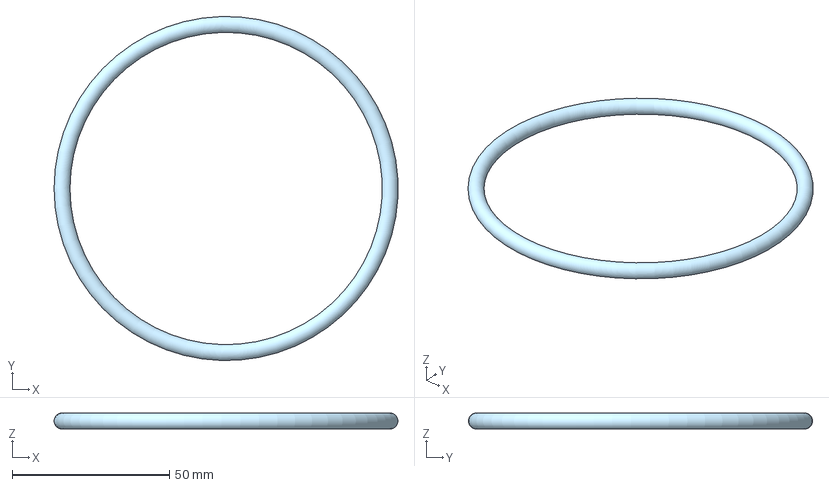
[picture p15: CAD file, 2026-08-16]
mechanical/cad/electronics-housing/electronics-housing-tpu-ring.step
109.4 x 109.4 x 5.08 mm

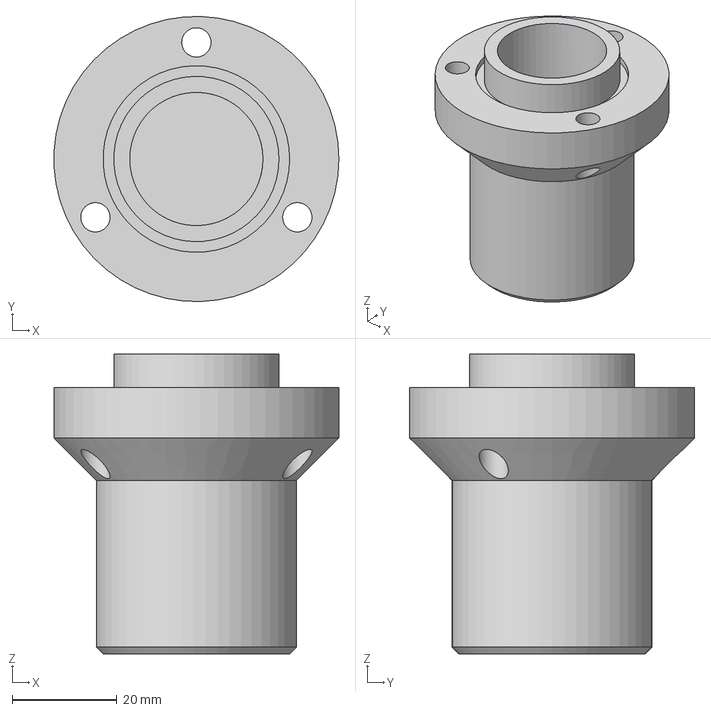
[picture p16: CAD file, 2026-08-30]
mechanical/cad/sensor-housing/sensor-housing-body-face-seal.step
54.3 x 54.3 x 57.1 mm

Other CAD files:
mechanical/cad/electronics-housing/electronics-housing-endcap-no-port.step
mechanical/cad/floatation/chassis-floatation-integrated-v3-part3.step
mechanical/cad/electronics-housing/electronics-housing-body.step
mechanical/cad/floatation/outer-octagon-shell.step
mechanical/cad/floatation/chassis-floatation-bolted-v3-part1.step
mechanical/cad/floatation/chassis-floatation-bolted-v3-part2.step
mechanical/cad/floatation/chassis-floatation-bolted-v5-wedge-bottom.step
mechanical/cad/floatation/chassis-floatation-bolted-v5-wedge.step
mechanical/cad/floatation/chassis-floatation-integrated-v3-part2.step
mechanical/cad/floatation/current/chassis-floatation-bolted-v4-chassis-cap.step
mechanical/cad/floatation/current/chassis-floatation-bolted-v4-chassis.step
mechanical/cad/floatation/current/chassis-floatation-bolted-v4-wedge-bottom.step
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

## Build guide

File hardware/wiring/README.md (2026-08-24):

# Wiring / Interconnect

`scout-reva-system-interconnect.svg` — system-level interconnect diagram (power nets, signal
nets, component blocks) derived from the Rev A schematic. Opens directly in any browser or
vector editor.

This is a communication/assembly aid, not an authoritative source — the KiCad schematic in
[../schematics/](../schematics/) wins if the two ever disagree.

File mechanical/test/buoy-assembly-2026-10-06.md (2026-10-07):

# Buoy Bottom Sections and First Glued Assembly — 2026-10-06

> **Summary** — John printed new bottom sections of the buoy and assembled everything built so
> far: wedges, chassis and bottom caps. The inside seams were glued with Gorilla Glue, and the
> assembly is taped to hold position while it cures. Marine epoxy goes on the outside once the
> glue has cured. Build record, not a test; no result yet.
>
> Part of [`mechanical/test/`](README.md). Related: [SCO-93](https://linear.app/scout1/issue/SCO-93)
> (chassis print), [SCO-75](https://linear.app/scout1/issue/SCO-75).

## What was done (John Ryan, 2026-10-06)

| Step | Detail |
|---|---|
| Printed | New bottom sections of the buoy |
| Assembled | Wedges, chassis and bottom caps, as built so far |
| Inside seams | Gorilla Glue (a polyurethane glue) |
| Outside seams | Marine epoxy, **after** the glue cures |
| While curing | Blue painter's tape over the top and down the sides to stop the parts shifting |

## Not yet recorded

- Which print version the parts are (v5 or v6 wedges, bottom section revision), printer, material.
- Glue cure time and the planned epoxy product.
- Which seams the glue and the epoxy are on, and whether any joint is left unbonded for
  service access.
- Whether a gap-fill or a leak/flotation check follows the bonding.

## Photos

Eighteen photos from 2026-10-06. "Open" photos show the assembly untaped with one sector open;
"taped" photos show it taped while curing. The open/taped labels were sorted by the blue tape
visible in each photo.

- [01, taped](buoy-assembly-2026-10-06-01-taped.jpg)
- [02, taped](buoy-assembly-2026-10-06-02-taped.jpg)
- [03, open](buoy-assembly-2026-10-06-03-open.jpg)
- [04, open](buoy-assembly-2026-10-06-04-open.jpg)
- [05, open](buoy-assembly-2026-10-06-05-open.jpg)
- [06, taped](buoy-assembly-2026-10-06-06-taped.jpg)
- [07, taped](buoy-assembly-2026-10-06-07-taped.jpg)
- [08, open](buoy-assembly-2026-10-06-08-open.jpg)
- [09, open](buoy-assembly-2026-10-06-09-open.jpg)
- [10, open](buoy-assembly-2026-10-06-10-open.jpg)
- [11, open](buoy-assembly-2026-10-06-11-open.jpg)
- [12, open](buoy-assembly-2026-10-06-12-open.jpg)
- [13, open](buoy-assembly-2026-10-06-13-open.jpg)
- [14, taped](buoy-assembly-2026-10-06-14-taped.jpg)
- [15, open](buoy-assembly-2026-10-06-15-open.jpg)
- [16, taped](buoy-assembly-2026-10-06-16-taped.jpg)
- [17, taped](buoy-assembly-2026-10-06-17-taped.jpg)
- [18, taped](buoy-assembly-2026-10-06-18-taped.jpg)

## 2026-10-07 — J-B Weld on the outside seams

John put **J-B Weld two-part epoxy** (from a syringe; the product line is not legible in the photos) across many of the exterior crevices of the assembled buoy. In the photos it is the white bead along the radial seams on top, around the central ring, and down the side seams. **More crevices still need it**; John did not say which ones are left. This is the outside bonding step the entry above says follows the glue cure. No leak or flotation check has been done yet.

Photos: [view 1](buoy-jb-weld-2026-10-07-01.jpg), [view 2](buoy-jb-weld-2026-10-07-02.jpg).

Not recorded: the epoxy's cure time, how long after the Gorilla Glue it went on, and whether this replaces the marine epoxy planned above.

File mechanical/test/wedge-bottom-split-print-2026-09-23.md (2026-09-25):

# Wedge Bottom Split Print and Printer Workaround, 2026-09-23

> **Summary** — The EPIC lab's medium Prusa failed, and a single wedge bottom takes over a day
> to print. John rigged a filament workaround on the medium Prusa, split the lean v5 wedge
> bottom CAD into two parts, and started the first half on a Prusa Mini. First layers were
> poor: some nozzle drag, and filament-feed resistance starved the bottom-layer infill for a
> stretch. The print was left running. **Outcome, 2026-09-24: the Prusa Mini prints failed** (see
> [Outcome](#outcome-2026-09-24)). Wedges printed on the larger printer came out well once
> PTFE-tube feed resistance was fixed. Tracked on
> [SCO-111](https://linear.app/scout1/issue/SCO-111).

---

## Printer status

| Machine | Location | State, 2026-09-23 |
|---|---|---|
| Medium Prusa | EPIC lab | **Failed, running on a workaround.** Its filament feeder had already been bypassed before today. John bypassed it again and set up a rolling filament stand inside the printer enclosure. Described by John as "sketchy but appeared to work". Not a proper repair; fix tracked on [SCO-114](https://linear.app/scout1/issue/SCO-114) |
| Prusa Mini | EPIC lab | Printing wedge-bottom half 1 |
| Large lab printer | — | Offline since the power-supply swap ([SCO-63](https://linear.app/scout1/issue/SCO-63)) |

**Why it matters:** each full wedge bottom takes over a day to print, and the buoy needs six
(one per 60° wedge). With the medium Prusa unreliable and the large printer offline, the
lab can't produce the flotation ring at the planned rate.

## CAD change: wedge bottom split in two

John split the [lean v5 wedge bottom](../cad/floatation/README.md#lean-wedge-bottom-v5--2026-09-10)
into two parts so each fits and finishes on a smaller printer.

**Split location (confirmed by John, 2026-09-23):** a single clean radial cut down the center
of the 60° segment, running from the outer radius to the inner radius. This gives two
matching 30° halves. The cut is plain, with no overlap, tab, or key, so the halves meet at a
flat butt joint.

**Not yet recorded:**

- **How the halves join.** Epoxy, bolts, or both. A flat butt joint has no mechanical
  interlock, so the bond carries everything.
- **STEP export of the halves.** Not committed yet. The committed
  `chassis-floatation-bolted-v5-wedge-bottom.step` is still the one-piece part.

**Open question: permanent design or print workaround?** The wedge bottom is the waterline
impact cap, and the impact analysis (Scenario C) relies on it being the thick part of the
shell. A seam through it adds a new leak path and a new weak line. The one-piece part is the
baseline until the team decides otherwise.

## First-half print observations

- **Bottom-layer quality was poor.** There was some nozzle dragging on the first layers.
- **Feed resistance.** At one point filament resistance stopped it feeding smoothly, which
  under-fed the bottom-layer infill.
- **Left running.** The part may come out with a weak or porous bottom skin, which is the
  underwater face.

## To check on 2026-09-24

- [x] Did the print finish? **No. It failed** (see below).
- [ ] Is the bottom skin continuous? Not applicable, no usable part.
- [ ] Printed mass of the half. Not available, still owed on SCO-111.
- [ ] Record the Mini's settings and print time for the half. Not recorded.

## Outcome, 2026-09-24

**Prusa Mini: failed, repeatedly.** John tried several times. Every attempt failed, ending in
the spaghetti mess in the photo below. Problems John saw:

- **Bed adhesion.** Parts would not stay stuck to the sheet.
- **Z calibration off.** First-layer height was wrong, which fits the nozzle drag seen on
  2026-09-23.
- "Many issues" beyond those two. Not broken down further.

The Mini is **not usable for wedge parts** until it is recalibrated. No usable split half
exists yet.

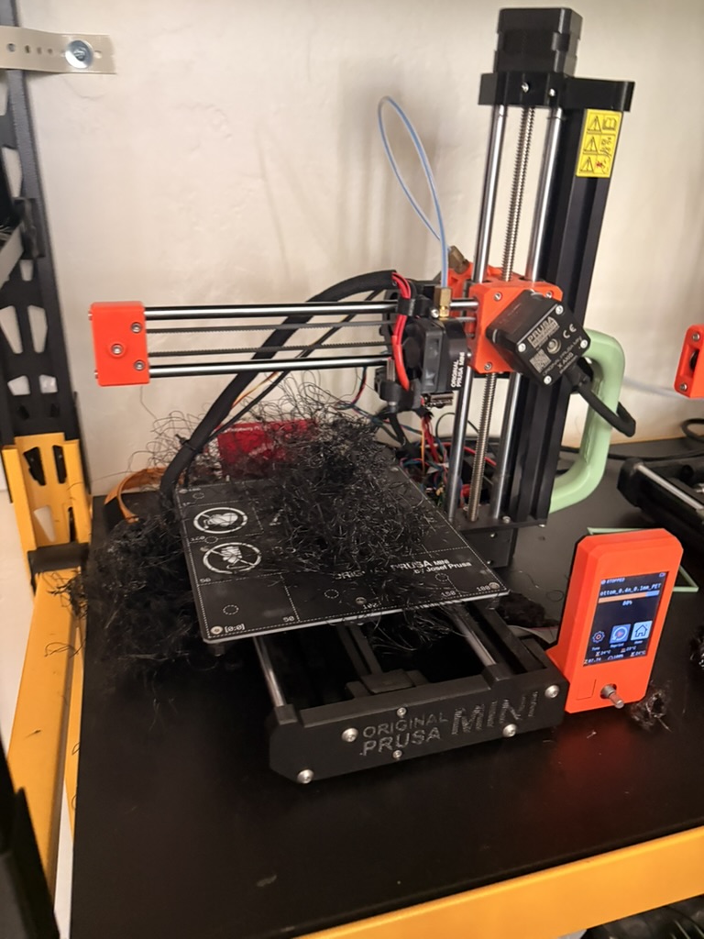
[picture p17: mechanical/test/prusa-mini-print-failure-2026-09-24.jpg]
Prusa Mini after a failed wedge-bottom half print, 2026-09-24


**Larger printer: wedges printed pretty well.** John reported that the larger printer turned
out good wedge prints. Filament met resistance in the PTFE tubes, and John fixed that.

**Not yet recorded:**

- Which larger printer this was. The medium Prusa on its workaround is assumed, since the
  large lab printer is offline ([SCO-63](https://linear.app/scout1/issue/SCO-63)).
- Whether it printed full one-piece wedge bottoms, split halves, or wedges.
- How the PTFE-tube resistance was fixed, and whether that fix closes
  [SCO-114](https://linear.app/scout1/issue/SCO-114).
- Print time and printed mass of the parts.

**What this means for the split.** The split existed only to fit the Mini. With the Mini
failing and the larger printer working, the one-piece wedge bottom stays the baseline. The
open question on SCO-111 is now weaker, because the split has no working printer.

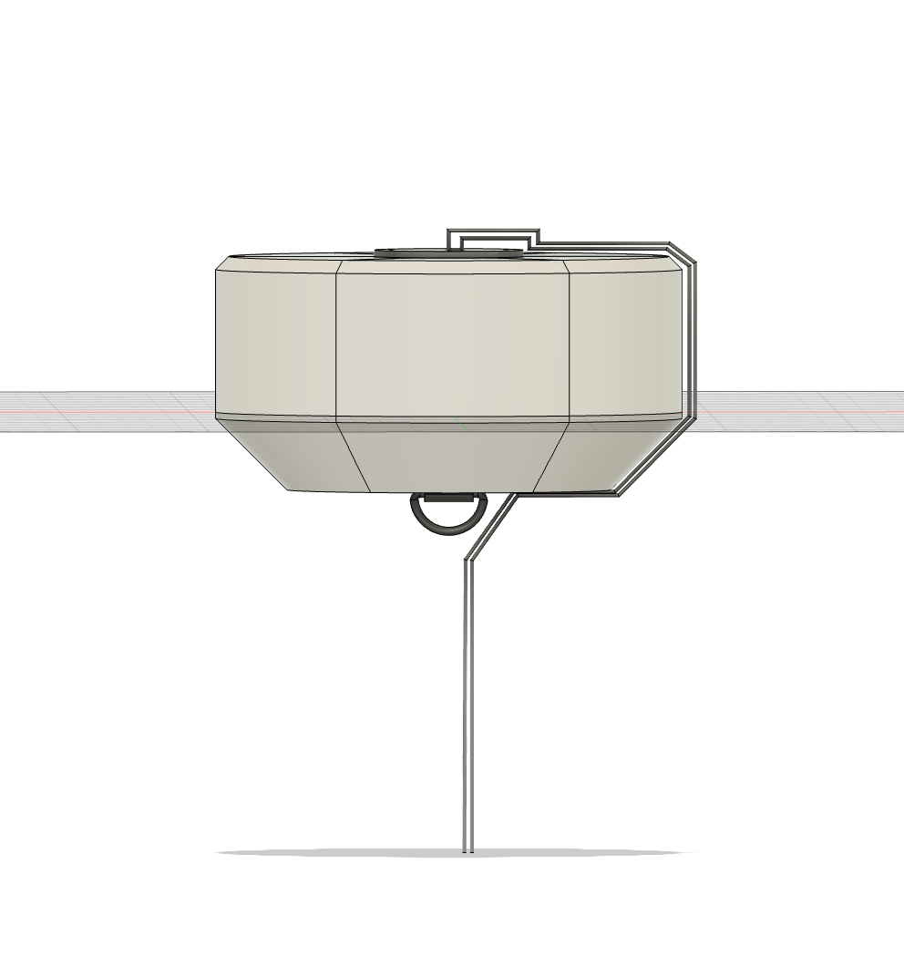
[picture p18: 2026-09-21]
assets/diagrams/buoy-assembly-cable-routing-2026-09-21.png

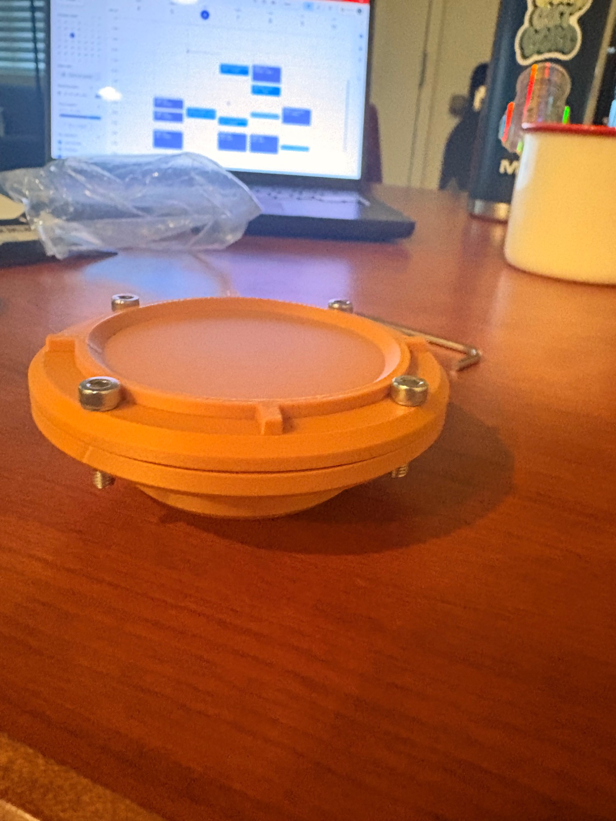
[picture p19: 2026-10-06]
mechanical/test/sensor-housing-oring-coupon-2026-10-06-run2-assembled-side.jpg

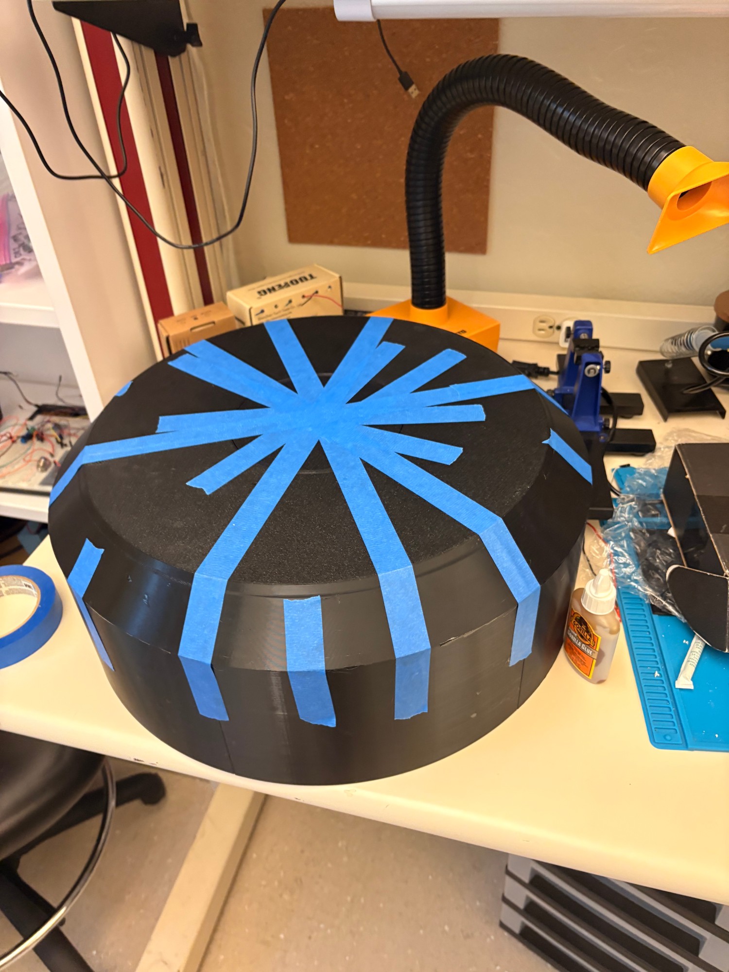
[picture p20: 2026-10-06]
mechanical/test/buoy-assembly-2026-10-06-17-taped.jpg

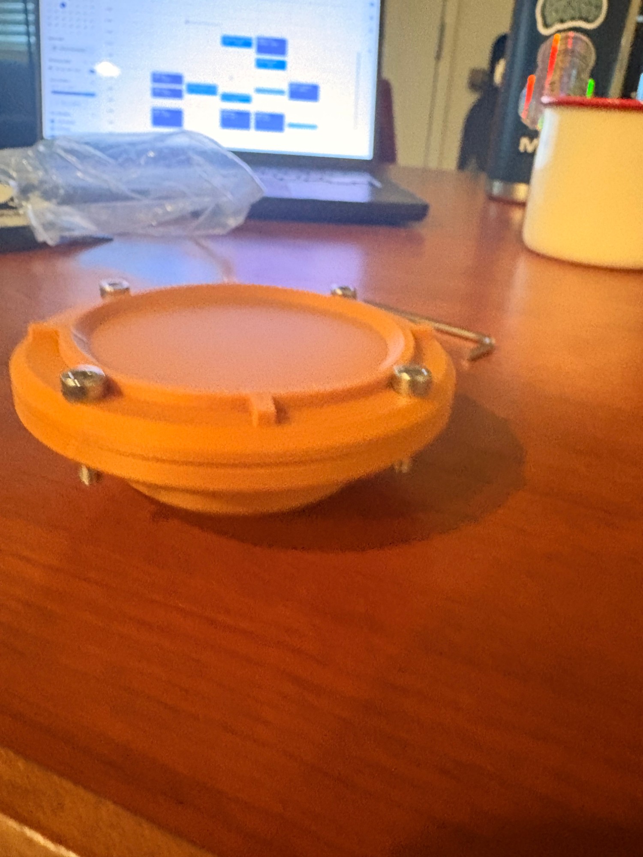
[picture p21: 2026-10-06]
mechanical/test/sensor-housing-oring-coupon-2026-10-06-run2-assembled-side-2.jpg

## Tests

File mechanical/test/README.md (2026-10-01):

# Test — Buoyancy, Structural, Pressure & Submersion Records

Buoyancy, waterline, structural (FEA), pressure, and submersion test records for the buoy
structure. First category populated 2026-08-17 with the initial floatation FEA pass.

**Owner:** GE lead (field & mechanical)

## Contents

**Start with the [risk-reduction register](risk-reduction-register.md)**: every prototype and
risk-reduction test, run and planned, with its benchmark and result in one table.

| Record | Date | Summary |
|---|---|---|
| [`sensor-housing-oring-coupon-2026-10-01.md`](sensor-housing-oring-coupon-2026-10-01.md) | 2026-10-01 | Short sensor-housing coupon to test the face seal with a purchased 3/16 in plumbing O-ring, groove sized for 25% squeeze. **Not yet run** (RR-12, [SCO-108](https://linear.app/scout1/issue/SCO-108)) |
| [`wedge-bottom-split-print-2026-09-23.md`](wedge-bottom-split-print-2026-09-23.md) | 2026-09-23 | Medium Prusa failed, running on a filament workaround. Lean v5 wedge bottom split into two parts, and half 1 started on a Prusa Mini. **2026-09-24: Mini prints failed repeatedly** (bed adhesion, Z calibration). The larger printer printed wedges well after a PTFE-tube feed fix ([SCO-111](https://linear.app/scout1/issue/SCO-111)) |
| [`sensor-housing-tpu-oring-failure-2026-09-12.md`](sensor-housing-tpu-oring-failure-2026-09-12.md) | 2026-09-12 | Extended (~1 week) submersion of the turbidity sensor-housing prototype, sealed with a TPU-printed O-ring (shortcut, not the specified AS568-137). **Fail** — water got in, though the poor ring held out most water for most of the week first. Decision: no further housing submersion tests until a real, purchased O-ring is on hand ([SCO-106](https://linear.app/scout1/issue/SCO-106)) |
| [`wedge-ring-buckling-check-2026-09-09.md`](wedge-ring-buckling-check-2026-09-09.md) | 2026-09-09 | Closed-form external-pressure buckling of the v5 wedge ring. **Bare** 0.095 in wall: `SF` ≈ 0.2–0.7 (fails). **Foam-backed:** `SF` ≈ 3–5. Confirms and quantifies "foam in before submersion". The epoxied 6-wedge ring is stiffer again — the confirming FEA is [SCO-71](https://linear.app/scout1/issue/SCO-71) / [SCO-73](https://linear.app/scout1/issue/SCO-73) |
| [`wedge-wall-thickness-structural-check-2026-09-07.md`](wedge-wall-thickness-structural-check-2026-09-07.md) | 2026-09-07 | Closed-form check of the v5 thinned wedge walls (outer 0.095 in / sides 0.063 in, 5.5 in height). **Both accepted on stress** — the six wedges form an epoxied closed monocoque ring (60° each, epoxied seams, foamed after ring assembly). Internal bracing web mandatory (DFM). The epoxied ring is the primary structure; foam is required backing against local/asymmetric loads, mandatory before submersion pending an assembly-level ring-buckling FEA (now quantified closed-form, see the row above). Impact ([SCO-71](https://linear.app/scout1/issue/SCO-71)) still to check |
| [`fea-mooring-load-cases.md`](fea-mooring-load-cases.md) | 2026-08-29 | **Tracker + results for LC2–LC9 + service** (all run 2026-08-29). Load, min SF, displacement, verdict per case + report links. **Buoy structure passes every case** (SF 10–1450); LC6/LC9 low-SF spots confirmed as stand-in-ring contact artifacts. Final 316 pad-eye re-run deferred |
| [`fea-mooring-lc2-vertical-uplift-2026-08-29.md`](fea-mooring-lc2-vertical-uplift-2026-08-29.md) | 2026-08-29 | LC2 detailed summary — 322 N vertical uplift, min SF 7.53, 0.012 mm. The LC3–LC9 reports are HTML-only; their results are in the tracker |
| [`waterproofing-submersion-test-2026-08-24.md`](waterproofing-submersion-test-2026-08-24.md) | 2026-08-24 | Bench submersion test, 3 articles: PLA sensor housing + TPU O-ring passed (~30 hr, dry); PETG print (low quality) and the electronics housing both failed |
| [`print-weight-verification-2026-08-24.md`](print-weight-verification-2026-08-24.md) | 2026-08-24 | Full slicer weigh-in of all five current bolted-v4 floatation parts. Retires the shared calibration factor; flags an unreconciled ~31% Wedge weight discrepancy against the 2026-08-21 measurement |
| [`fea-floatation-side-load-2026-08-17.md`](fea-floatation-side-load-2026-08-17.md) | 2026-08-17 | First FEA pass: floatation wedges + bottom caps under a 300 N side load. Min safety factor 25.4 |

Each record is a Markdown summary (key results, methodology, caveats) linking to the full
native report export. The native export is the source of record for anything not summarized —
open it directly for full contact/mesh/result detail per component.

## Native report format

FEA studies run in **Autodesk Fusion** are exported as a self-contained interactive HTML
report (Fusion's built-in "Studies Report"). Per
[CONVENTIONS.md → File formats](../../docs/CONVENTIONS.md#file-formats), CAD and schematics
keep both a native source and a neutral export; there is no separate native Fusion study file
committed here (the design's native source is the shared Onshape/Fusion document — see
[`mechanical/cad/README.md`](../cad/README.md#native-source)), so the HTML report itself is
the committed artifact, paired with a Markdown summary for diffability and quick reading.

## What's not yet covered

**Update 2026-08-29** — the LC1–LC9 framework loads are computed
([`force-budget.md`](../../docs/engineering/buoy-structural/force-budget.md)) and **LC2–LC9 +
a service case have been run** — full results in [`fea-mooring-load-cases.md`](fea-mooring-load-cases.md).
**The buoy structure passes every case** (min SF 10–1450). LC6/LC9 show min SF 1.5–1.7 at the
`3076T33` stand-in ring's contact interface — examined and confirmed as a mesh/contact artifact,
not the buoy. The final 316 pad-eye + LC7's moment get a dedicated re-run before deployment.

Still to do, per [design-notes.md](../../docs/hub/design-notes.md):

- Max expected loads calculated from first principles — **methodology now formalized** in
  [Buoy Structural Load Framework](../../docs/engineering/buoy-structural/structural-load-framework.md)
  (corrected LC1–LC9 cases), but not yet run: several inputs are still open (mooring
  scope/line weight, design wave values, final Cd/Cm/Ca coefficients — see the framework's
  §12). The 300 N side load used in the 2026-08-17 study below was a test input, not a derived
  design load.
- FEA across additional planes/directions (top load, torsion, mooring-point pull)
- Thermal analysis
- A validated safety-factor target (this pass used **SF ≥ 4 as a pass/fail check for this
  study only** — not yet an established, derived requirement). **2026-09-25:** left as a
  study-only check. SCO-71 was closed on the v5 FEA margins plus a single-wedge
  [drop test](wedge-drop-test-2026-09-25.md), without deriving a formal target

**2026-08-18 — validation-target pivot.** The SF 25.4 result above, read against the
project's cost target, was judged over-engineered — see
[`mechanical/cad/floatation/README.md`](../cad/floatation/README.md#cross-section-fit-test-print-and-a-validation-target-pivot--2026-08-18).
Future studies target **impact survivability at controlled cost** (grounding, drops, ideally a
boat strike) rather than continuing to push the static-load safety factor. FEA impact/drop-load
simulation and bench impact tests on printed samples are planned:
[SCO-71](https://linear.app/scout1/issue/SCO-71).

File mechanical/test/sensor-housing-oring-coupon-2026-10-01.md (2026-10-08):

# Sensor Housing O-Ring Coupon — 2026-10-01

> **Summary** — A shortened print of the turbidity sensor housing's flanged dry chamber and
> bolted cap, made only to test the face seal with a **purchased** O-ring. The last housing soak
> (RR-07, 2026-09-12) failed with a TPU-printed ring, and a real ring was the precondition for
> testing again. Register entry **RR-12** in the
> [risk-reduction register](risk-reduction-register.md).
>
> Part of [`mechanical/test/`](README.md). Tracks [SCO-108](https://linear.app/scout1/issue/SCO-108).

## Specimen

| Item | Value |
|---|---|
| Geometry | Shortened sensor-housing body: lower spigot, flared flange, flat cap held by 3 bolts (Fusion, 2026-10-01) |
| O-ring | Hardware-store plumbing ring, **ID 2-1/4 in × OD 2-5/8 in × 3/16 in (0.1875 in) section, measured** |
| Ring material | Not confirmed. Plumbing rings are usually nitrile (Buna-N). The design choice is silicone (decision 2026-09-08), so this tests the groove, not the final elastomer |
| Print material | PETG |

## Groove design (static face seal, external pressure)

| Dimension | Value | Basis |
|---|---|---|
| Groove depth | **0.141 in (3.57 mm)**, range 0.131–0.150 | 25% squeeze (20–30% range) |
| Groove width | **0.262 in (6.65 mm)**, range 0.255–0.270 | ~75% gland fill |
| Groove ID | **2.250 in (57.15 mm)** | Equal to ring ID, so the ring seats on the inner wall under external pressure |
| Groove OD | **2.774 in (70.46 mm)** | Groove ID + 2 × width |

The same 25% squeeze / ~75% fill targets as the AS568-142 design in the
[sensor housing README](../cad/sensor-housing/README.md). Two layout checks:

- The solid face between the Ø52 mm chamber and the groove ID is only ~2.6 mm. Print it solid.
- At the previous Ø74.4 mm bolt circle, the bolt holes would break into this groove. The bolt
  circle needs to be about Ø82 mm or larger (flange OD about Ø98 mm), depending on bolt size.
  Confirm against the CAD.

## Procedure

1. Caliper-check the printed groove depth, width and ID before assembly. Record actual values.
2. Dry paper towel inside, ring seated with no lubricant (or silicone grease, recorded), bolts
   torqued evenly.
3. Submerge at ≥ 0.3 m in salt water mixed to ~35 ppt, at room temperature.
4. Check at 24 hr. If dry, continue to 1 week.

## Pass benchmark (provisional, pending SCO-139)

Paper towel **dry at 24 hr**, and dry again at 1 week.

## Result

**Run 2026-10-06 — FAIL (slightly damp inside at 24 hr; not flooded).**

| Item | Value |
|---|---|
| Soak | 24 hr submerged, salt water (salinity and depth not recorded) |
| Lubricant | None (no grease) |
| Bolt torque | Not recorded (tightened by hand) |
| Fasteners | 3 stainless socket-head screws into brass heat-set inserts |
| Groove measurements | Not recorded |
| Outcome | Interior **slightly damp**, no standing water. Misses the "dry at 24 hr" benchmark |

**Observation (the cause of the leak, per John):** with the cap bolted down, the two faces
touched snugly **at each bolt**, but the cap **flexed between the bolts**, leaving a visible gap
between the faces midway between each pair of bolts. The ring was therefore compressed less, or
not at all, in those sections. The 3-bolt pattern on a flat cap is not stiff enough to hold the
face seal closed all the way round. The failure is in the joint stiffness, not in the ring or
the groove depth.

Not yet tested: whether more bolts, a thicker or ribbed cap, or a stiffer cap material closes
the gap. Candidates only — none chosen.

Photos (2026-10-06): [assembled](sensor-housing-oring-coupon-2026-10-06-assembled.jpg),
[side, gap visible between the bolts](sensor-housing-oring-coupon-2026-10-06-side.jpg),
[top](sensor-housing-oring-coupon-2026-10-06-top.jpg),
[body with the ring seated in the groove, 3 heat-set inserts](sensor-housing-oring-coupon-2026-10-06-body-groove.jpg).

## Run 2 — 2026-10-06 (in the water, result due ~2026-10-07)

This is the **PLA turbidity test** introduced the morning of 2026-10-06. It is PLA only because the
PETG ran out (confirmed by John).

Second coupon, changed in response to the run-1 flexing ([CAD](sensor-housing-oring-coupon-2026-10-06-run2-cad.jpg)).

| Item | Run 1 | Run 2 |
|---|---|---|
| Print material | PETG | **PLA** (PETG ran out — a stand-in, and it changes the stiffness) |
| Groove | ID 2.250 in, OD 2.774 in | Same |
| O-ring | 3/16 in section, ID 2-1/4 in | Slightly larger ring that still fits the groove (exact size not recorded) |
| Bolts | 3 | **4** |
| Cap | Flat | **Radial ribs on top**, 4, midway between the bolts |
| Lubricant / torque | None / not recorded | Not recorded |

**Early observation (dry, before the soak):** the cap **still flexes and flares between the bolts**,
though less than run 1. John's read: the ribs need to sit further out for even compression, and an
outer rim ring is under consideration.

**Confound to remember:** four things changed at once (material, ring size, bolt count, ribs), so
a pass or fail will not say which one mattered.

Photos (2026-10-06, before the soak; orange PLA, black ring, paper towel as the moisture indicator):
- Ring seated in the body groove, 4 brass heat-set inserts, towel inside:
  [view 1](sensor-housing-oring-coupon-2026-10-06-run2-ring-in-groove.jpg),
  [view 2](sensor-housing-oring-coupon-2026-10-06-run2-ring-in-groove-2.jpg),
  [blurred](sensor-housing-oring-coupon-2026-10-06-run2-ring-in-groove-blurred.jpg)
- [Cap top: 4 radial ribs and 4 bolt holes](sensor-housing-oring-coupon-2026-10-06-run2-cap-top-ribs.jpg)
- [Body with towel beside the cap](sensor-housing-oring-coupon-2026-10-06-run2-body-and-cap.jpg)
- Assembled, 4 bolts: [side](sensor-housing-oring-coupon-2026-10-06-run2-assembled-side.jpg),
  [side 2](sensor-housing-oring-coupon-2026-10-06-run2-assembled-side-2.jpg)
- [Assembled, held up: a dark seam line is visible between the cap and body flange](sensor-housing-oring-coupon-2026-10-06-run2-assembled-seam-gap.jpg)

_Result (reported by John 2026-10-07): **the PLA pod leaked.** Hours to failure and where the water entered were not given; record them if known._

## Run 3 — printed and in the water 2026-10-07

After the run 2 leak John built a new version: **6 bolts, a thicker cap, and thicker ribs** supporting the cap. CAD: [`sensor-housing-assembly-v9.step`](../cad/sensor-housing/sensor-housing-assembly-v9.step). The cap thickness is a second change on top of the bolt count, so a pass will not say which of the two mattered.

**What John did on 2026-10-07:** redesigned the pod (about 30 min), then printed it, pressed in the six heat-set inserts, assembled it with six bolts and put it in the water to start the test (about 35 min). The test clock started when it went in; the result is due after the 24 hr check ([RR-15](risk-reduction-register.md)).

| Item | Run 2 | Run 3 |
|---|---|---|
| Bolts | 4 | **6**, evenly spaced |
| Cap | Ribbed, thinner | **Thicker, with thicker ribs** (dimensions not recorded) |
| Print | Orange PLA | Orange print as in run 2; material not stated |
| Result | Leaked | **Pending** |

Not recorded: the time it went in the water, the water depth and salinity, the O-ring size and whether it was lubricated, bolt torque.

Photos (2026-10-07):
- [Body with the six brass heat-set inserts pressed in, before assembly](sensor-housing-oring-coupon-2026-10-07-run3-body-six-inserts.jpg)
- [Assembled: six bolts and the ribbed cap](sensor-housing-oring-coupon-2026-10-07-run3-assembled-six-bolts.jpg)

**Result: failed 2026-10-08. The whole pod flooded, despite six bolts** (per John; where the water got in, the paper-towel state and the ring used were not recorded). Three failures in a row now (3, 4, then 6 bolts) say that more bolts and a stiffer cap were not the main problem. Likely cause: the ring. John later confirmed the ring he uses is **OD 2-5/8 in, ID 2-1/4 in, so 3/16 in (4.76 mm) cross-section**, about double the 2.62 mm of the AS568-137/142 ring the pod groove was sized for. If this ring was in run 3 it could not seat in that groove. That is an inference: the ring in run 3 was not recorded.

### Original decision (2026-10-06)

John decided on **6 evenly spaced bolts** for the next cap, after the gap between the bolts seen in
run 1 and not closed in run 2. Registered as RR-15. The raised hoop over the groove and a bolt
circle moved closer to the groove were suggested but are **not decided**, so run 3 is a bolt-count
change only unless John adds them.

## Run 4 — 2026-10-08 (matched groove, body supplied)

Not yet printed or in the water. John supplied a new, shorter body ([`sensor-housing-body-short-v1.step`](../cad/sensor-housing/sensor-housing-body-short-v1.step), Fusion export 2026-10-08, in inches), shortened to save filament. Registered as [RR-16](risk-reduction-register.md).

**Ring (confirmed by John):** OD 2-5/8 in (66.68 mm), ID 2-1/4 in (57.15 mm), cross-section 3/16 in (4.76 mm). A hardware-store ring (Everbilt Medium O-Ring Assortment, 6 pcs, 2-1/2 to 3-1/2 in OD), not an AS568 standard size. Elastomer unknown.

**Groove, read from the STEP geometry:**

| Feature | Value |
|---|---|
| Groove inner / outer diameter | Ø2.20 in (55.9 mm) / Ø2.74 in (69.6 mm) |
| Groove floor | about 0.135 in (3.4 mm) below the mating face, inferred from vertex heights; about 28% squeeze |
| Bolts | 6 holes, Ø0.22 in (5.6 mm), on a Ø3.10 in (78.7 mm) circle |
| Flange / height | Ø3.50 in (88.9 mm) / about 0.6 in (15 mm) |

The groove follows the standard static face-seal guidance (about 25–30% squeeze, about 77% gland fill), recalled from the Parker handbook and not yet checked against it. The cap is not in this file; it must match the body's groove face and bolt circle.

What changes against run 3: the ring and groove now match. The body is also shorter. Pass benchmark is unchanged (dry paper towel after 24 hr at ≥ 0.3 m in ~35 ppt salt water). Result: pending.

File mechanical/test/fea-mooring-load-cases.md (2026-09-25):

# FEA — Mooring / Structural Load Cases LC1–LC9

> **Summary** — Tracker + results for the FEA runs of the corrected load cases defined in the
> [Buoy Structural Load Framework](../../docs/engineering/buoy-structural/structural-load-framework.md)
> and computed in [`force-budget.md`](../../docs/engineering/buoy-structural/force-budget.md).
> **LC2–LC9 + a service case were run 2026-08-29** (John Ryan, Fusion static stress, custom PETG
> profile, McMaster `3076T33` steel tie-down ring as the pad-eye stand-in).
>
> **Headline: the buoy structure passes every case (min SF 30–1450).** LC6/LC9 show min SF
> 1.5–1.7, but John examined the reports (2026-08-29) and confirmed those are **contact-edge
> artifacts on the `3076T33` stand-in ring's bonded interface — not the buoy**. The buoy PETG
> (wedges, chassis, pad-eye boss) is not the limiter in any case. **Sufficient for now.** The
> final 316 pad-eye + its real mounted interface still gets a dedicated re-run before deployment
> (panel Action A1, [SCO-69](https://linear.app/scout1/issue/SCO-69) / [SCO-73](https://linear.app/scout1/issue/SCO-73)).
> See [§ Reading](#reading).
>
> Loads are at the *proposed* environmental design set (SCO-73 not yet signed off).
> Axes: **Z** = buoy vertical (up +), **X**/**Y** = horizontal.

## Results — v5 re-check (2026-09-25)

Five runs by John Ryan on the v5 geometry (lean floatation, 3076T33 stand-in ring still in
place), at the **v5 loads** from [`force-budget.md` § v5 geometry reassessment](../../docs/engineering/buoy-structural/force-budget.md#v5-geometry-reassessment-2026-09-09).
The 30° LC9 run was not done by choice. The 3076T33 ring's base plate therefore sees the snap
load only at 0°, and the seam direction is covered only by the LC5 hull load (run 1).

**Setup as run:** Fusion stock **"ABS Plastic"** (E 2240 MPa, ν 0.38, **yield 20 MPa**) — *not*
the custom PETG profile (yield 35 MPa). Stiffness matches, so stresses and displacements stand;
every buoy SF below is re-based to PETG as `35 / σ` (×1.75 on Fusion's ABS figure). Density
1.06 (should be 1.27; immaterial for static). Mesh 10%, parabolic, no refinement. Reports 1–3
were exported with empty result tables, so values come from the plot legends.

| Run | Case | Load **as run** | Peak (legend) | Buoy PETG stress | Buoy SF (PETG) | Verdict |
|---|---|---|---:|---:|---:|---|
| 1 | LC5 wave+current, toward a seam | `(−285.8, 165, 0)` N = 330 N @ 30° | VM 19.4 MPa (local spot) | ≤ ~4 MPa at the load patch | ≥ ~8.8 (1.8 if the spot is PETG) | **pass**; max disp 0.27 mm |
| 2 | LC5 wave+current | `(−330, 165, 0)` N = 369 N @ 27° (12% over design) | VM 47.3 MPa, in the steel ring | ≤ ~5 MPa | ≥ ~7; steel ring 4.4 | **pass** |
| 3 | LC8 hydrostatic, 5 m | 0.05 MPa inward, all external faces incl. wedge shells | 1st principal 9,780 MPa — point singularity | **5–10 MPa at mid-panel of each wedge outer wall** (SF plot: green 2–4 on ABS) | **3.5–7** | **pass** — real result: unfoamed thin walls bending between supports |
| 4 | LC9 snap + LC7 moment | `(−371, 0, −450)` N + moment **42 N·mm** about `(0, 11.5, −40.4)` | table: VM 24,782 MPa, 907 mm disp; plot: VM 116 MPa at the ring | ≤ ~12 MPa | ≥ ~3; steel ring 1.8 | **pass** — artifact confirmed by John (see ¹) |
| 5 | Ring buckling (Structural Buckling) | 0.05 MPa inward on the wedge ring | load multiplier **1.873** (modes 2–3: 1.885, 1.914) | — | BLF 1.87 | **pass, thin margin** (see ²) |

¹ The 907 mm displacement is a **mechanism, not a stress spike**: the folding 3076T33 ring body
is bonded to its base plate at one small face and pivots. The buoy PETG around it stays
low-stress. The **moment was entered as 42 N·mm, not 42 N·m (42,000 N·mm), and mostly about Z**,
so LC7 was not exercised in FEA. Closed by hand instead: worst bolt of the 4 × 1/4-20 pattern
(31.75 × 28.6 mm) = 450/4 + 42/0.03175/2 = **774 N** → 38 MPa in the bolt (SF > 5), 3.2 MPa
washer bearing on PETG (SF ≈ 11), 2.6 MPa pull-through shear at an assumed 5 mm wall (SF ≈ 7.7).

² Linear buckling at 1.873 × 50 kPa = **94 kPa ≈ 9.3 m** with **no foam**. A 0.5 imperfection
knock-down for printed thin shells gives ~47 kPa ≈ **4.7 m — at the 5 m test spec**. In service the
float sits 2.5 in deep, so this governs only the pressure test and storm push-under. **Foam fill
is structurally required** for the 5 m pressure test (closed-form, foam-backed: SF 3–5, per the
[ring-buckling check](wedge-ring-buckling-check-2026-09-09.md)). Pressure-test with foam installed.

Reports (images stripped):
[run 1](fea-mooring-lc5-wave-current-seam-v5-2026-09-25.html) ·
[run 2](fea-mooring-lc5-wave-current-v5-2026-09-25.html) ·
[run 3](fea-mooring-lc8-hydrostatic-v5-2026-09-25.html) ·
[run 4](fea-mooring-lc9-snap-v5-2026-09-25.html) ·
[run 5](fea-ring-buckling-v5-2026-09-25.html)

**Reading (v5):** the v5 structure passes every load case. The lowest *real* buoy SF is ~3.5,
in the thin wedge walls under LC8 with no foam. These are static and buckling cases. No impact
or drop case was run. [SCO-71](https://linear.app/scout1/issue/SCO-71) was closed on these
results plus a single-wedge [drop test](wedge-drop-test-2026-09-25.md). Still owed: the final 316 pad-eye run with LC7's moment applied
correctly and the ring joined to its base plate, re-run on the custom PETG profile.

## Results (2026-08-29)

| Case | Load **as run** | Applied to | min SF | max disp | max contact pressure | Fusion verdict |
|---|---|---:|---:|---:|---:|---|
| **LC2** taut-line uplift | `(0, 0, −322)` N | pad-eye ring | **7.53** | 0.012 mm | — | pass (banner artifact) |
| **LC3** current | `(0, 14, 0)` N | wetted hull band | **1450** | 0.003 mm | 0.02 MPa | pass — trivial (14 N) |
| **LC4** wave | 185 N horizontal | wetted float band | **70.4** | 0.139 mm | 0.46 MPa | pass |
| **LC5** wave+current, **face** | 440 N horizontal (`+Y`) | one wedge face | **29.6** | 0.331 mm | 1.09 MPa | pass |
| **LC5(2)** wave+current, **edge** | 440 N horizontal, `(−220, 381, 0)` | a wedge-to-wedge edge | **65.0** | 0.093 mm | 1.03 MPa | pass |
| **LC6** combined resultant | `(−490, 0, −392)` N ‖627 N @ 51°‖ | pad-eye boss | 1.66¹ | 0.107 mm | 40.6 MPa¹ | artifact at the stand-in ring — buoy PETG OK |
| **LC7** overturning | `(−490, 0, 0)` N — **moment NOT applied** | pad-eye boss | 2.03¹ | 0.105 mm | 36.4 MPa¹ | incomplete run; artifact-limited |
| **LC8** hydrostatic | 0.05 MPa (50 kPa) external, 5 m head | sealed boundaries | **9.98** | 0.40 mm | 3.04 MPa | pass |
| **LC9** mooring snap | `(−490, 0, −644)` N ‖810 N @ 37°‖ | pad-eye boss | 1.49¹ | 0.109 mm | 50.4 MPa¹ | artifact at the stand-in ring — buoy PETG OK |

¹ Min SF and peak contact pressure in LC6/LC7/LC9 are **contact-singularity artifacts** at the
`3076T33` steel stand-in ring's bonded interface (coarse mesh, no refinement, generic-steel
properties on a placeholder part) — **examined and confirmed by John, 2026-08-29**. The buoy
PETG is not the limiter in any case (peak VM ~124–139 MPa is in the steel ring; if PETG were
limiting, LC9 min SF would be ~0.25). These re-run with the final 316 pad-eye and its real
mounted interface before deployment.
| **Service** down-load | `(0, 0, −200)` N | chassis-cap top | **290** | 0.018 mm | 0.14 MPa | pass — trivial |

Mesh (where reported): 114,564 nodes / 62,994 elements, parabolic. Material: custom PETG (E 2240
MPa, ν 0.38, yield 35 MPa, UTS 45 MPa; density 1.06 g/cm³ — carried from the old ABS profile,
should be 1.27) + Fusion generic steel (yield 207 MPa) for the 3076T33 ring.

Reports (embedded result-plot images stripped to keep the repo light — the tables/numbers are
intact; regenerate plots from the Fusion source if needed):

- [`fea-mooring-lc2-vertical-uplift-2026-08-29.html`](fea-mooring-lc2-vertical-uplift-2026-08-29.html) ([summary](fea-mooring-lc2-vertical-uplift-2026-08-29.md))
- [`fea-mooring-lc3-current-2026-08-29.html`](fea-mooring-lc3-current-2026-08-29.html)
- [`fea-mooring-lc4-wave-2026-08-29.html`](fea-mooring-lc4-wave-2026-08-29.html)
- [`fea-mooring-lc5-wave-current-face-2026-08-29.html`](fea-mooring-lc5-wave-current-face-2026-08-29.html)
- [`fea-mooring-lc5-wave-current-edge-2026-08-29.html`](fea-mooring-lc5-wave-current-edge-2026-08-29.html)
- [`fea-mooring-lc6-combined-2026-08-29.html`](fea-mooring-lc6-combined-2026-08-29.html)
- [`fea-mooring-lc7-overturning-2026-08-29.html`](fea-mooring-lc7-overturning-2026-08-29.html)
- [`fea-mooring-lc8-hydrostatic-2026-08-29.html`](fea-mooring-lc8-hydrostatic-2026-08-29.html)
- [`fea-mooring-lc9-snap-2026-08-29.html`](fea-mooring-lc9-snap-2026-08-29.html)
- [`fea-mooring-service-download-2026-08-29.html`](fea-mooring-service-download-2026-08-29.html)

## Reading

- **The buoy structure passes every case.** LC3–LC5 (current, wave, wave+current up to 440 N),
  the service down-load, and LC8 (hydrostatic, 5 m) all pass with min SF ≥ 10 and sub-mm
  displacement. The floatation and chassis are not a concern — consistent with the
  "over-engineered wedges" finding from the mass/freeboard work.
- **LC6/LC7/LC9's low min SF (1.5–2.0) are artifacts, not a real failure path.** John examined
  the reports on 2026-08-29 and confirmed: the peak stress and 40–50 MPa contact pressure are a
  **contact singularity at the `3076T33` stand-in ring's bonded interface** — coarse mesh (10 %,
  no adaptive refinement), a bonded-contact edge, and generic Fusion "Steel" properties on a
  placeholder part. The buoy PETG (wedges, chassis, pad-eye boss) is nowhere near yield in any
  case; displacements stay ~0.1 mm. **This is sufficient for now** — the buoy structure is
  validated against the LC1–LC9 loads.
- **What's deferred, not dropped:** the final **316 pad-eye** and its real mounted interface
  (through-bolt / deep inserts into the 76 mm solid section) haven't been modelled. Re-running
  LC6/LC7/LC9 with that geometry — LC7 with its 70 N·m moment, LC6 at the correct
  `(−490, 0, −322)` — is the panel's Action A1 sign-off, tracked on
  [SCO-69](https://linear.app/scout1/issue/SCO-69) / [SCO-73](https://linear.app/scout1/issue/SCO-73),
  required before deployment.

## Next steps (deferred — not blocking; buoy structure is validated for now)

1. **Re-run LC6 / LC7 / LC9 with the final 316 pad-eye geometry** (not the 3076T33 stand-in),
   its real mounted interface into the 76 mm solid section, **LC7's 70 N·m moment applied**, and
   LC6 at `(−490, 0, −322)`. This is the panel Action A1 sign-off for the mooring attachment.
2. Use a refined mesh at the pad-eye/boss contact so the min SF there is real, not a singularity.
3. Reconcile the PETG density (1.06 → 1.27 g/cm³) and set an explicit derived Safety-Factor
   target (framework §11).
4. Run the governing lateral cases at a second azimuth (LC5 has face + edge; do the same for
   LC6/LC9 once the geometry is final).

## Conventions for these runs

- **Material:** custom PETG profile (E 2240 MPa, ν 0.38, yield 35 MPa, UTS 45 MPa). Density
  1.06 g/cm³ (from the old ABS profile) — should be 1.27; immaterial for static cases but
  reconcile. Re-run governing cases for ABS / ASA per [SCO-64](https://linear.app/scout1/issue/SCO-64).
- **Attachment part:** McMaster `3076T33` steel tie-down ring is the stand-in; swap for the
  final 316 pad-eye ([SCO-69](https://linear.app/scout1/issue/SCO-69)).
- **Safety-factor target:** set an explicit derived target (framework §11).

## Upload workflow (when a run finishes)

1. Export the Fusion Studies Report as HTML → `mechanical/test/fea-mooring-lc<N>-<slug>-<date>.html`.
   Strip embedded base64 images before committing (keeps the repo light; tables/numbers stay).
2. Add / update the row in the Results table above.
3. Update [`force-budget.md`](../../docs/engineering/buoy-structural/force-budget.md)'s load-case
   status table.
4. If a result changes a structural conclusion, add a [`design-notes.md`](../../docs/hub/design-notes.md)
   row and a [`journal/`](../../docs/hub/journal/) snapshot.

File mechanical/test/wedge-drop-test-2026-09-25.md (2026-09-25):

# Wedge Drop Test — 2026-09-25

> **Summary** — John Ryan dropped a single printed v5 flotation wedge. It showed **no
> deformation**. John judged this sufficient to close the impact-validation work
> ([SCO-71](https://linear.app/scout1/issue/SCO-71)), together with the 2026-09-25 v5 FEA
> re-check. This is a one-sample, informal bench check, not a controlled impact test.
>
> Part of [`mechanical/test/`](README.md). Tracks [SCO-71](https://linear.app/scout1/issue/SCO-71).

## What was done

| Item | Value |
|---|---|
| Date | 2026-09-25 |
| Tester | John Ryan (GENG) |
| Specimen | One printed v5 flotation wedge, single part (not the assembled ring) |
| Drop height | Not recorded |
| Impact surface and orientation | Not recorded |
| Foam fill | Not recorded |
| Samples | 1 |
| Result | **No visible deformation, cracking, or delamination** |

## Reading

- **Pass**, on John's judgement as GENG lead. He finds one sample sufficient.
- It is consistent with the FEA: the lowest real buoy SF at v5 loads is ~3.5 (PETG), and every
  hull load case passes ([FEA results § v5 re-check](fea-mooring-load-cases.md#results--v5-re-check-2026-09-25)).
- **What it does not show.** It is one sample, and the height, surface, and orientation were
  not recorded, so the drop energy is unknown. It was one wedge, not the bolted-and-epoxied ring
  with the lean wedge bottom. So it is not a quantitative survivability target and not a
  boat-strike test. The [impact survivability analysis](../../docs/engineering/buoy-structural/impact-survivability-analysis.md)
  Scenario C (drop onto the base, lean wall section) was not specifically exercised.
- **The SF ≥ 4 placeholder** in this folder's [README](README.md) stays a study-only check. The
  team has accepted the v5 margins (min real SF ~3.5 unfoamed, higher with foam) plus this drop
  as sufficient, rather than deriving a formal SF target.

## If this is revisited

Record the drop height, surface, and orientation. Test a foam-filled wedge on its wedge bottom,
drop it onto the base, and use at least 3 samples. That would give the impact analysis a
measured energy to calibrate against.

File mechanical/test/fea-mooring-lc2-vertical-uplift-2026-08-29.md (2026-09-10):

# FEA — LC2 Mooring Vertical Uplift, 2026-08-29

> **Summary** — First run of the corrected [FEA load cases](../../docs/engineering/buoy-structural/force-budget.md#computed-load-cases).
> **LC2** = the taut-line vertical uplift the mooring / pad-eye sees if the buoy is pulled fully
> under: **322 N straight down (−Z) at the attachment**, chassis heat-set region fixed. Run in
> Autodesk Fusion (2704.1.53) with a **custom PETG material profile** (see below) and a
> **McMaster 3076T33 steel tie-down ring** as the attachment part. Full interactive report:
> [`fea-mooring-lc2-vertical-uplift-2026-08-29.html`](fea-mooring-lc2-vertical-uplift-2026-08-29.html).
>
> **Remaining load cases LC3–LC9 are not yet run** — tracked in
> [`fea-mooring-load-cases.md`](fea-mooring-load-cases.md); John Ryan is running and will upload
> them (top priority).

---

## Setup

| | |
|---|---|
| Tool | Autodesk Fusion (2704.1.53), Static Stress study "LC2" (Fusion report title "L2 / Studies") |
| Model | Heat-set attachment Part 1:1, Part 2:1–6, Part 3:1–6 (the chassis / wedge heat-set region) + `3076T33_Tie-Down Ring:1` |
| Load case | **LC2** — `Force2` = **322.00 N**, vector **X 0 / Y ~0 / Z −322.00 N** (straight down) — matches [`force-budget.md` LC2](../../docs/engineering/buoy-structural/force-budget.md#lc2--taut-line-vertical-uplift----322-n-vertical-at-the-u-bolt) (the net reserve buoyancy at the light build) |
| Constraint | `Fixed2` — Ux/Uy/Uz fixed at the chassis heat-set reference |
| Contacts | 33 bonded sets across the heat-set parts and the tie-down ring |
| Mesh | Parabolic solids, **114,564 nodes / 62,994 elements**, 10 % element size, curved elements, 60° max turn angle |
| Convergence | 0 adaptive refinement steps, 20 % results-convergence tolerance (baseline accuracy) |

### Materials

**PETG — custom profile** (John Ryan, built in Fusion 2026-08-29):

| Property | Value | Note |
|---|---|---|
| Density | **1.060×10⁻⁶ kg/mm³ (1.06 g/cm³)** | ⚠️ **carried over from the 2026-08-17 ABS profile — PETG is ~1.27 g/cm³.** Immaterial for this static case (gravity is negligible next to the 322 N load), but reconcile before any mass-relevant study. The [mass budget](../../docs/engineering/buoy-structural/mass-and-buoyancy-budget.md) uses 1.27 g/cm³ |
| Young's Modulus | 2240 MPa | same as the 2026-08-17 ABS run |
| Poisson's Ratio | 0.38 | |
| **Yield Strength** | **35.00 MPa** | conservative for PETG (published ~50 MPa) — raised from the ABS profile's 20 MPa |
| **Ultimate Tensile Strength** | **45.00 MPa** | raised from the ABS profile's 29.6 MPa |
| Thermal conductivity | 1.60×10⁻⁴ W/(mm·K) | |
| Thermal expansion | 8.57×10⁻⁵ /K | |
| Specific heat | 1500 J/(kg·K) | |

**Steel** (the 3076T33 tie-down ring, Fusion generic): E 210 GPa, ν 0.30, yield 207 MPa, UTS
345 MPa, ρ 7.85 g/cm³. A stand-in — the real part is being specified on
[SCO-69](https://linear.app/scout1/issue/SCO-69) (316 for the build; 3076T33 is a steel
tie-down ring used here the same way 304 stood in for the U-bolt geometry earlier).

## Results

| Result | Min | Max |
|---|---|---|
| Safety factor | **7.53** | 196,602 (local/singularity) |
| Von Mises stress | 1.8×10⁻⁴ MPa | **27.49 MPa** |
| 1st principal stress | −2.70 MPa | 34.07 MPa |
| Normal ZZ | −14.38 MPa | 32.21 MPa |
| **Total displacement** | 0 mm | **0.012 mm** |
| Reaction force (Z, max nodal) | — | 31.97 N |
| Contact pressure | 0 MPa | 12.55 MPa |
| Equivalent strain | 0 | 4.0×10⁻⁴ |

**Reading:** the attachment is **very stiff and low-stress at LC2** — 12 µm peak displacement,
min SF 7.5, peak von Mises ~27 MPa (in the steel ring; the PETG stays well below its 35 MPa
yield). This is a comfortable pass against any conventional structural target (SF ≥ 2–4).

> **Flagged:** Fusion's Guided-Results banner reads *"the design is expected to bend permanently
> or break"* — which is **inconsistent with the reported min SF of 7.53** and the 12 µm
> displacement. Most likely the study's Safety-Factor *target* is set unusually high, or it is
> Fusion's canned below-target guidance rendering regardless. The raw numbers pass. Worth
> confirming the SF target setting on the next run so the banner matches the result.

## What this does and doesn't establish

- **Does:** confirms the mooring attachment region does not come close to yielding under the
  322 N taut-line vertical uplift (LC2), at the custom PETG profile.
- **Doesn't:** cover LC3–LC9 (current, wave, combined, overturning moment, hydrostatic, snap) —
  those are the load cases that actually load the attachment *laterally* and with a moment, and
  LC9 (the ~810 N snap) is the governing one. Doesn't use the final pad-eye part (3076T33 is a
  stand-in). Doesn't reconcile the 1.06 vs 1.27 g/cm³ PETG density. Uses a stress singularity
  (SF max 196,602) that inflates the reported SF range — read the min, not the max.

## Next steps

1. **LC3–LC9** — run and upload (top priority). Especially **LC9 snap (~810 N at 37° from
   vertical)** and **LC6/LC7** (combined + overturning moment) — LC2 alone is not sufficient to
   sign off the attachment.
2. Reconcile the PETG density (1.06 → 1.27 g/cm³) and confirm the yield/UTS against a PETG
   datasheet or a printed-coupon tensile test.
3. Set an explicit, derived Safety-Factor target (framework §11) so the Guided-Results verdict
   is meaningful.
4. Swap the 3076T33 stand-in for the final 316 pad-eye once chosen ([SCO-69](https://linear.app/scout1/issue/SCO-69)).

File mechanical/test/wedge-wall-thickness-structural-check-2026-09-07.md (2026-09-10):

# Wedge Wall-Thickness Structural Check — 2026-09-07

> **Summary** — First-principles structural check of the **thinned flotation-wedge walls**
> (outer curved wall **0.095 in / 2.41 mm**, radial side walls **0.063 in / 1.60 mm**) John
> Ryan iterated to during the 2026-09-03→05 slicing passes, at the new 5.5-in wedge height
> ([SCO-110](https://linear.app/scout1/issue/SCO-110)). Runs the wedge-relevant load cases from
> [`force-budget.md`](../../docs/engineering/buoy-structural/force-budget.md) (LC3–LC5 wave/current,
> LC8 hydrostatic) plus two loads that framework doesn't cover — **foam-fill expansion pressure**
> and **print/handling flex** — as closed-form hand calculations.
>
> **Verdict:** the **outer wall at 0.095 in is acceptable and is the floor** — do not thin it
> further. The **side walls at 0.063 in are accepted** — each is paired face-to-face with the
> neighbouring wedge in an **epoxied closed ring** (John confirmed: exactly 60° wedges,
> epoxied seams, foamed after ring assembly — [§5.0](#50-the-radial-faces-are-paired--the-side-walls-are-not-isolated-panels)),
> so it sees no through-thickness service pressure and the bonded 3.2 mm seam is both a
> compression-ring path and a stiff stringer. The internal bracing web John added is
> **load-bearing and mandatory, not just a print aid**. The foam fill is retained as
> **required backing for the outer wall** (foam in before any submersion) — conservatively,
> pending an assembly-level buckling check now that the ring is bonded ([§8](#8-the-foam-and-the-failure-philosophy)).
>
> **[Rev 2, 2026-09-07]** — the side-wall recommendation was made conditional after John Ryan
> pointed out the radial faces are paired; see [§5.0](#50-the-radial-faces-are-paired--the-side-walls-are-not-isolated-panels)
> and [§5.5](#55-confirmed-by-john-2026-09-07).
>
> **[Rev 3, 2026-09-07 — resolves the side walls]** John confirmed all three
> [§5.5](#55-confirmed-by-john-2026-09-07) questions: each wedge is **exactly 60°** (faces tile
> in contact), the **seams are epoxied**, and **foam is poured after the wedges are bolted into
> the ring**. Together that makes the six wedges an **epoxied closed monocoque ring** — the
> radial seams are true 3.20 mm composite bonds carrying moment and tension, not just contact —
> and the foam-fill pressure is reacted by the neighbouring (already-bonded) wall.
> **→ The side walls at 0.063 in are accepted, no remaining conditions.** The 0.080 in
> alternative is moot. The internal bracing web stays mandatory (it fixed the print). The
> outer-wall foam requirement is retained conservatively pending an assembly-level buckling
> check — see [§8](#8-the-foam-and-the-failure-philosophy).
>
> **Not a substitute for FEA or the [SCO-71](https://linear.app/scout1/issue/SCO-71) impact
> test.** These are conservative closed-form bounds to answer "is this wall spec sane before
> committing print time," not a validated sign-off. Impact/boat-strike survivability is
> materially more sensitive to wall thickness now and is explicitly out of scope here.
>
> Part of the [Knowledge Hub](../../docs/hub/README.md)'s test records. Feeds
> [SCO-110](https://linear.app/scout1/issue/SCO-110) (wedge resize), informs
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

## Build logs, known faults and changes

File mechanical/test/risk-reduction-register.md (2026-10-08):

# Mechanical Prototype & Risk-Reduction Test Register

> **Summary** — One list of every mechanical prototype and risk-reduction test S.C.O.U.T. has run
> or plans to run: what risk each test retires, what kind of prototype it uses, the pass
> benchmark, and the result. Set up 2026-10-01 at the request of Jes Kuczenski (GENG advisor),
> who asked for testing to be layered and benchmarked before results are read
> ([meeting 2026-09-30](../../docs/planning/meeting-notes.md)).
>
> Part of [`mechanical/test/`](README.md). Detailed write-ups stay in their own records; this
> page is the index. Benchmarks are **provisional** until
> [SCO-139](https://linear.app/scout1/issue/SCO-139) sets them, and the stage plan comes from
> [SCO-140](https://linear.app/scout1/issue/SCO-140).

## How to use this page

- **Add a row before the test runs**, with its benchmark, then fill in the result afterwards.
  A test whose pass mark is written down after the result isn't a test.
- **Prototype type:** *coupon* (a small piece testing one feature), *looks-like* (form and
  fit), *works-like* (function), or *analysis* (closed-form or FEA, no hardware).
- **IDs are permanent.** `RR-NN`, numbered in order and never reused.

## Tests run

| ID | Date | Test | Risk retired | Type | Benchmark | Result | Record |
|---|---|---|---|---|---|---|---|
| RR-01 | 2026-08-17 | Flotation side-load FEA (300 N) | Wedges and caps fail under side load | analysis | SF ≥ 4 | **Pass** — min SF 25.4 | [record](fea-floatation-side-load-2026-08-17.md) |
| RR-02 | 2026-08-24 | Print weight verification (all five v4 flotation parts) | Mass budget is wrong | manufacturing | Slicer mass within ~10% of measured | **Partial** — ~31% wedge discrepancy unreconciled | [record](print-weight-verification-2026-08-24.md) |
| RR-03 | 2026-08-24 | Bench submersion, 3 articles (TPU-printed O-rings) | Printed housings leak | coupon / looks-like | Dry inside after the soak | **Mixed** — PLA sensor housing passed (~30 hr); low-quality PETG print and electronics housing failed | [record](waterproofing-submersion-test-2026-08-24.md) |
| RR-04 | 2026-08-29 | Mooring load-case FEA LC2–LC9 + service | Hull fails under mooring, wave, current, snap loads | analysis | SF ≥ 4 | **Pass** — SF 10–1450 | [record](fea-mooring-load-cases.md) |
| RR-05 | 2026-09-07 | Wedge wall-thickness closed-form check | Thinned v5 walls overstressed | analysis | Stress within allowable | **Pass** on stress; internal web required | [record](wedge-wall-thickness-structural-check-2026-09-07.md) |
| RR-06 | 2026-09-09 | Wedge ring external-pressure buckling | Unfoamed ring buckles when submerged | analysis | SF ≥ 2 | **Bare fails** (SF 0.2–0.7); **foam-backed passes** (SF 3–5) | [record](wedge-ring-buckling-check-2026-09-09.md) |
| RR-07 | 2026-09-12 | ~1-week submersion, sensor housing with TPU-printed O-ring | Printed O-ring is good enough | works-like | Dry inside after 1 week | **Fail** — water got in. No more housing soaks until purchased rings are on hand | [record](sensor-housing-tpu-oring-failure-2026-09-12.md) |
| RR-08 | 2026-09-23 | Split wedge-bottom print, Prusa Mini vs larger printer | Parts can't be printed reliably | manufacturing | Part prints to spec first time | **Mini fails** (adhesion, Z); **larger printer passes** | [record](wedge-bottom-split-print-2026-09-23.md) |
| RR-09 | 2026-09-25 | v5 FEA re-check + ring buckling at v5 | v5 geometry change breaks load margins | analysis | SF ≥ ~3.5 | **Pass** — min real SF ~3.5 PETG unfoamed | [record](fea-mooring-load-cases.md#results--v5-re-check-2026-09-25) |
| RR-10 | 2026-09-25 | Single-wedge drop | Wedge cracks on handling or impact | coupon | No visible damage | **Pass** — 1 sample, height not recorded | [record](wedge-drop-test-2026-09-25.md) |
| RR-11 | 2026-09-29 | Large-angle stability calculation (STEP geometry) | Buoy stable upside down / capsizes | analysis | Rights itself from any angle | **v5 fails** (stable inverted) → **v6 with 24 in ballast passes** | [calculator](../simulations/buoy-stability/README.md) |

⚠️ **Not yet recorded:** John has run several informal "is the paper towel wet inside the
capsule" checks and more drop tests than RR-10. Add them as rows if dates and outcomes can be
recovered.

## In progress

| ID | Started | Test | Risk retired | Type | Benchmark (provisional) | Status | Tracks |
|---|---|---|---|---|---|---|---|
| RR-12 | 2026-10-01 | **Short sensor-housing coupon, face seal with a purchased O-ring** | The face-seal groove leaks with a real ring (RR-07 failed with a printed one) | coupon | Dry paper towel inside after **24 hr at ≥ 0.3 m in ~35 ppt salt water**, then 1 week | **Fail** 2026-10-06 — slightly damp at 24 hr; cap flexed between the 3 bolts, so the ring lost compression there | [record](sensor-housing-oring-coupon-2026-10-01.md), [SCO-108](https://linear.app/scout1/issue/SCO-108) |
| RR-14 | 2026-10-06 | **Sensor-housing coupon run 2: PLA, 4 bolts, ribbed cap, slightly larger ring** | Stiffening the cap closes the gap between the bolts that failed RR-12 | coupon | Dry paper towel inside after 24 hr at ≥ 0.3 m in ~35 ppt salt water | **Failed 2026-10-07: pod leaked** | [record](sensor-housing-oring-coupon-2026-10-01.md#run-2--2026-10-06-in-the-water-result-due-2026-10-07) |
| RR-15 | 2026-10-06 | **Sensor-housing coupon run 3: 6 evenly spaced bolts, thicker cap, thicker ribs** | Six bolts plus a stiffer cap close the gap between the bolts that opened in RR-12 and RR-14 | coupon | Dry paper towel inside after 24 hr at ≥ 0.3 m in ~35 ppt salt water | **Failed 2026-10-08: pod flooded completely** despite 6 bolts ([CAD](../cad/sensor-housing/sensor-housing-assembly-v9.step)) | [decision](../../docs/hub/decision-log.md) |
| RR-16 | 2026-10-08 | **Sensor-housing coupon run 4: groove cut for the real ring (3/16 in CS), 6 bolts, shorter body** | The ring and groove were mismatched in RR-15 (a 4.76 mm ring in a groove cut for a 2.62 mm one); a matched groove at about 28% squeeze seals | coupon | Dry paper towel inside after 24 hr at ≥ 0.3 m in ~35 ppt salt water | Body supplied 2026-10-08 ([CAD](../cad/sensor-housing/sensor-housing-body-short-v1.step)); not yet in the water | [record](sensor-housing-oring-coupon-2026-10-01.md#run-4--2026-10-08-matched-groove-body-supplied), [SCO-108](https://linear.app/scout1/issue/SCO-108) |
| RR-13 | 2026-09-30 | v5 chassis print on the dedicated printer | Chassis can't be printed round and flat enough to seal | manufacturing | Seal faces flat and round within ±0.2 mm | Printing | [SCO-93](https://linear.app/scout1/issue/SCO-93) |

## Tests still to do

Ordered roughly by when the risk bites. Benchmarks are placeholders for
[SCO-139](https://linear.app/scout1/issue/SCO-139).

| Test | Risk retired | Type | Benchmark (placeholder) | Tracks |
|---|---|---|---|---|
| Saltwater capsules at 1, 2 and 3 wall layers, with and without marine sealant | Printed walls weep through layer lines | coupon | Dry after 1 week at ~35 ppt | [SCO-141](https://linear.app/scout1/issue/SCO-141) |
| Electronics housing AS568-043 fit check | Ring doesn't fit the printed groove | coupon | Seats without stretch > 3% or pinching | [SCO-106](https://linear.app/scout1/issue/SCO-106), [SCO-105](https://linear.app/scout1/issue/SCO-105) |
| Foam-fill trials on spare wedges | Foam voids, or expansion cracks the shell | coupon | No voids on sectioning, no shell cracks | [SCO-76](https://linear.app/scout1/issue/SCO-76) |
| Cable gland and epoxy-potted lead penetration | Leaks where cables enter the dry chamber | coupon | Dry after 1 week soak | [SCO-53](https://linear.app/scout1/issue/SCO-53), [SCO-144](https://linear.app/scout1/issue/SCO-144) |
| Assembled buoy float check: waterline and freeboard | Mass/freeboard model is wrong | looks-like | Freeboard within ±0.5 in of the 4.27 in model | [SCO-124](https://linear.app/scout1/issue/SCO-124) |
| Self-righting / tilt test from 90° and 180° | Buoy stays capsized | works-like | Rights itself unaided from any angle | [SCO-82](https://linear.app/scout1/issue/SCO-82), [SCO-125](https://linear.app/scout1/issue/SCO-125) |
| Drop test of the assembled ring with 1.5 in caps | Lean wedge-bottom cracks on launch | looks-like | No cracks; height, surface and orientation recorded | [SCO-71](https://linear.app/scout1/issue/SCO-71) follow-up |
| Proof load of the mooring attachment and ballast-arm root | Through-bolts or backing plate pull through PETG | works-like | Holds ~1.5× LC9 snap (~1.2 kN) with no permanent set | [SCO-82](https://linear.app/scout1/issue/SCO-82), [SCO-75](https://linear.app/scout1/issue/SCO-75) |
| Pressure test of the sealed housings to max site depth | Seals leak at 8 m | works-like | Dry at ≥ 8 m equivalent (~0.8 bar) for 24 hr | [SCO-82](https://linear.app/scout1/issue/SCO-82) |
| Long-duration soak of the integrated buoy, in parallel with other work | Slow leaks or water uptake over weeks | works-like | Internal humidity stable for 4+ weeks | [SCO-140](https://linear.app/scout1/issue/SCO-140) |
| Pool test (float, self-righting, LoRa through water) | Behaves differently in open water than in a bin | works-like | All of the above in one deployment | [SCO-143](https://linear.app/scout1/issue/SCO-143) |

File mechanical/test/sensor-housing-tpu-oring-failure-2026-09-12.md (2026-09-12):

# Turbidity Sensor Housing — Extended Submersion Failure, 2026-09-12

> **Summary** — John opened the turbidity sensor housing prototype after an extended
> submersion and found it **not waterproof**. The seal was a **TPU-printed O-ring** — a
> known, deliberate shortcut for this article, not the specified off-the-shelf AS568-137 ring
> — and is the suspected cause. The ring held reasonably well for roughly a week before
> meaningful water got in, which matters for how the failure reads (see
> [What this does and doesn't establish](#what-this-does-and-doesnt-establish)). **Decision:**
> no further housing submersion testing until a real, purchased O-ring is on hand — see
> [SCO-106](https://linear.app/scout1/issue/SCO-106).

---

## Method

Informal field/bench check, not the controlled indicator-paper method used in the
[2026-08-24 test](waterproofing-submersion-test-2026-08-24.md): the assembled housing was left
submerged, then opened and inspected. No moisture-indicator paper or duration log was set up
going in, so timing below is John's recollection ("almost exactly a week"), not a timestamped
start/stop.

**Seal:** a **TPU-printed O-ring**, used because it was easier to produce short-term — the same
deliberate shortcut as the [2026-08-24 bench test](waterproofing-submersion-test-2026-08-24.md#method),
not the specified off-the-shelf **AS568-137** ring. The formal prototype is intended to use the
purchased ring once it's sourced ([SCO-106](https://linear.app/scout1/issue/SCO-106)).

**Article:** the printed turbidity sensor-housing prototype (body ↔ cap joint, 3-bolt pattern
with an O-ring visible at the mating face) — assumed to be the current
[face-seal remodel](../cad/sensor-housing/README.md#face-seal-remodel--2026-08-29)
(`sensor-housing-body-face-seal` + `sensor-housing-sealed-cap-v2`) based on the photo, but not
independently confirmed against a specific STEP revision.

**Photo:** shared in chat, not yet saved to the repo — add it here once available (same gap the
2026-08-18 wedge cross-section fit-test photo had; see
[floatation/README.md](../cad/floatation/README.md)).

## Result

❌ **Fail** — water had gotten into the housing by the time it was opened.

**Nuance worth keeping, not smoothing over:** the ring was, in John's own assessment, **very
poor quality**, and yet the housing kept out *most* water for close to a week before failing
meaningfully. Read together, that's consistent with a **slow leak from an inconsistent seal**
(the printed ring's dimensional variability let some water past at a low rate) rather than an
immediate, wide-open failure — a materially different failure mode than the 2026-08-24 PETG
article, which failed outright on a stringy print. This test doesn't distinguish which of
those two failure modes actually happened here (no interim checks were done), but the
"held for most of a week, then failed" behavior is itself a data point worth recording as-is.

## Decision

**No further submersion testing on this housing until a real, off-the-shelf O-ring is on
hand.** John's reasoning: the TPU-printed ring's inconsistency is the leading suspect for this
failure, so further tests on printed-ring seals would keep re-testing the same confound rather
than validating the actual face-seal design. This directly reinforces why
[SCO-108](https://linear.app/scout1/issue/SCO-108) (the formal re-test) is written to require
the *specified* rings, not printed stand-ins, and why it's gated on
[SCO-106](https://linear.app/scout1/issue/SCO-106) (choose the elastomer and order).

## What this does and doesn't establish

- **Does:** add a second, independent data point (after the
  [2026-08-24 test](waterproofing-submersion-test-2026-08-24.md)) that a TPU-printed O-ring is
  an unreliable stand-in for the specified AS568-137 ring — this time on the current face-seal
  geometry, over a much longer duration (~1 week vs. ~30 hours), and failing rather than
  passing. Confirms the housing was actually put in water, not just designed and left
  untested (see the correction to `facts.md`'s "neither housing has been submersion-tested"
  claim, now stale for the sensor pod specifically).
- **Doesn't:** validate or invalidate the **face-seal design itself** — groove dimensions,
  squeeze %, and flange stiffness (the open [SCO-91](https://linear.app/scout1/issue/SCO-91)
  acceptance criteria) are still unverified, because the seal actually under test was a printed
  ring, not the specified one. Doesn't pin down whether the failure was a slow weep the whole
  time or held dry for most of the week and failed late — no interim inspection was done.
  Doesn't resolve the [O-ring manufacturing method decision](../../docs/hub/decision-log.md)
  (off-the-shelf, decided 2026-08-17) — it's a second point of informal evidence in the
  direction that decision already assumed, not new grounds to revisit it.

## Next steps

1. **Order the real AS568-137 (and AS568-043) O-rings** — [SCO-106](https://linear.app/scout1/issue/SCO-106),
   currently the blocker for any further housing submersion work.
2. Once the real ring is on hand, re-run the formal [SCO-108](https://linear.app/scout1/issue/SCO-108)
   re-test with a logged start/stop time and, ideally, an interim check partway through — this
   test's biggest gap was not knowing whether the failure was gradual or sudden.
3. Add the photo to this record once it's saved into the repo.
4. Confirm which STEP revision the tested article actually matches (assumed face-seal remodel
   above — worth a quick check against the physical part if there's any doubt).

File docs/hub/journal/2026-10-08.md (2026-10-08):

# State Snapshot — 2026-10-08

> **Summary** — Dated snapshot of where S.C.O.U.T. stood on this day. Snapshots are append-only
> history; the always-current view is [`status.md`](../status.md).
>
> Part of the [Knowledge Hub](../README.md).

---

**Phase:** 1 — Subsystem Bring-Up (2026-09-07 – 2026-10-16)

## Changed 2026-10-08

- The Gantt replan (PR #163) merged: an MVP before winter break, target 2026-12-04.
- The sensor-pod cap no longer has a pilot spigot, so
  [SCO-109](https://linear.app/scout1/issue/SCO-109) was closed as moot and dropped from the
  Gantt. Recorded in the [decision log](../decision-log.md).
- **RR-15 failed**: the pod flooded completely with 6 bolts. The ring turned out to be a
  hardware-store ring with a 3/16 in (4.76 mm) cross-section, double the 2.62 mm the groove was
  cut for. A new body with a matched groove (about 28% squeeze) is registered as
  [RR-16](../../../mechanical/test/risk-reduction-register.md), not yet in the water.
- SCO-106 (O-ring fit) and SCO-139 (MVP benchmarks) closed; see the [decision log](../decision-log.md).
- Housing fixed at 4.4 in ID × 5 in tall ([SCO-49](https://linear.app/scout1/issue/SCO-49)),
  clearing the old FEA blocker. [SCO-73](https://linear.app/scout1/issue/SCO-73) is re-scoped to FEA of the new ballast stem (waits on [SCO-125](https://linear.app/scout1/issue/SCO-125)); the earlier LC1–LC9 runs stand.
  Chassis printed, mass/freeboard and stability finished, chassis load path done, foam covers the
  failure cases, cap cable gland merged into [SCO-68](https://linear.app/scout1/issue/SCO-68),
  Prusa XL dropped. See [`status.md`](../status.md) and the [decision log](../decision-log.md).
- Permitting researched for the Kaneohe Bay deployment, after Hannah Barkley's reply: see
  [Hawaii Deployment Permitting](../../research/hawaii-deployment-permitting.md). Lightest options
  are attended anchor-free tests and connecting to an existing authorized site; anything anchored
  needs the Corps first. Nothing has been confirmed by an agency yet; written determinations are
  the next step.

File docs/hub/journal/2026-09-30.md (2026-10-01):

# State Snapshot — 2026-09-30

> **Summary** — Dated snapshot of where S.C.O.U.T. stood on this day. Snapshots are append-only
> history; the always-current view is [`status.md`](../status.md).
>
> Part of the [Knowledge Hub](../README.md).

---

**Phase:** 1 — Subsystem Bring-Up (2026-09-07 – 2026-10-16)

## Where the project stands

First joint meeting with both faculty advisors (Kuczenski, GENG; Yang, ECEN). The v5 chassis was
printing during the meeting, so the first full assembly follows. The advisors' main message:
set measurable benchmarks and a layered test plan now, because the schedule is tight.

## Changed 2026-09-30

- **One joint weekly advisor meeting** replaces the tentative Tuesday Kuczenski slot.
- **Power path reopened:** a primary lithium cell with no solar is now weighed against LiFePO₄ +
  solar ([SCO-10](https://linear.app/scout1/issue/SCO-10)). Isabella brings the measured power
  budget to Shoba on 2026-10-02 ([SCO-116](https://linear.app/scout1/issue/SCO-116)).
- **Testing work filed:** benchmarks ([SCO-139](https://linear.app/scout1/issue/SCO-139)), test
  protocol ([SCO-140](https://linear.app/scout1/issue/SCO-140)), saltwater capsule tests
  ([SCO-141](https://linear.app/scout1/issue/SCO-141)), backup test site
  ([SCO-143](https://linear.app/scout1/issue/SCO-143)).

## Still open

- Exterior cable routing ([SCO-144](https://linear.app/scout1/issue/SCO-144)); modular multi-depth
  rod vs ADR-0003 ([SCO-145](https://linear.app/scout1/issue/SCO-145)).
- Hydrophone part ([SCO-8](https://linear.app/scout1/issue/SCO-8)); combined parts order
  ([SCO-115](https://linear.app/scout1/issue/SCO-115)); electronics component list
  ([SCO-70](https://linear.app/scout1/issue/SCO-70)).

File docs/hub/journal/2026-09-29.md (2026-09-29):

# State Snapshot — 2026-09-29

> **Summary** — Dated snapshot of where S.C.O.U.T. stood on this day. Snapshots are append-only
> history; the always-current view is [`status.md`](../status.md).
>
> Part of the [Knowledge Hub](../README.md).

---

**Phase:** 1 — Subsystem Bring-Up (2026-09-07 – 2026-10-16)

## Where the project stands

The buoy was found to float stably upside down, and the design now rights itself from any angle.
The v6 assembly and a committed stability calculator back that up.

## Changed 2026-09-28/29

- **Chassis prints upright** so the seal faces come out round (PR #152).
- **Electronics housing is flange-style**, and the flange caps the chassis. First-pass sizing:
  Ø4.375 in tube, Ø4.000 in opening, AS568-247 seal ([SCO-128](https://linear.app/scout1/issue/SCO-128)).
- **Stability rebuilt on STEP geometry.** The v5 buoy (3 in caps, no ballast): GM 7.1 in, vanishes
  at ~90°, **stable inverted**. Maximum hydrostatic righting (~4.8 N·m) is far below LC7 (~42 N·m),
  which contradicts §8 and is flagged for [SCO-82](https://linear.app/scout1/issue/SCO-82).
- **Fix decided:** 24 in ballast arm ([SCO-129](https://linear.app/scout1/issue/SCO-129)), 1.5 in
  caps ([SCO-130](https://linear.app/scout1/issue/SCO-130)), 316 pipe 4816K51 + 6040T57/T56 mount +
  backing plate ([SCO-131](https://linear.app/scout1/issue/SCO-131), [SCO-132](https://linear.app/scout1/issue/SCO-132)).
  v6 with 2.6 kg lead: 11.40 kg, freeboard 4.27 in, GM 12.8 in, self-rights from any angle.
- **Chassis print set:** 6 walls, 25% gyroid, 808 g ([SCO-133](https://linear.app/scout1/issue/SCO-133)).
- **v6 full assembly committed** ([`full-buoy-assembly-v6.step`](../../../mechanical/cad/full-buoy-assembly-v6.step)).
- **Calculator committed:** [`mechanical/simulations/buoy-stability/`](../../../mechanical/simulations/buoy-stability/README.md),
  with dated results and an interactive explorer.

## Still open

- LC7/LC9 re-run with the mooring on the pipe collar ([SCO-135](https://linear.app/scout1/issue/SCO-135)).
- Lead vs. the reef permit ([SCO-136](https://linear.app/scout1/issue/SCO-136)); part numbers for the swivel, U-bolt and O-ring ([SCO-137](https://linear.app/scout1/issue/SCO-137)).
- Flange-to-chassis seal ([SCO-68](https://linear.app/scout1/issue/SCO-68)); freeboard model doc update ([SCO-124](https://linear.app/scout1/issue/SCO-124)); SCO-71 drop test with 1.5 in caps.

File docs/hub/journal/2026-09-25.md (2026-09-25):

# State Snapshot — 2026-09-25

> **Summary** — Dated snapshot of where S.C.O.U.T. stood on this day. Snapshots are append-only
> history; the always-current view is [`status.md`](../status.md).
>
> Part of the [Knowledge Hub](../README.md).

---

**Phase:** 1 — Subsystem Bring-Up (2026-09-07 – 2026-10-16)

## Where the project stands

The v5 buoy structure has now been checked in FEA and passes. The lean wedge bottom has a real
slicer weight, and every buoyancy number carries it.

## Changed today

- **v5 FEA re-check, 5 runs, all pass.** The lowest real buoy SF is ~3.5 (PETG), in the unfoamed
  thin wedge walls under the 5 m hydrostatic case. Ring buckling came out at load factor 1.87
  with no foam, which makes **foam fill structurally required** for the 5 m pressure test. See
  [FEA results § v5 re-check](../../../mechanical/test/fea-mooring-load-cases.md#results--v5-re-check-2026-09-25).
- **Lean wedge bottom sliced: 207.06 g** (4 walls, 0.18 mm layers, 15% gyroid, ~5 h 9 m). That
  is heavier than v4's 181.21 g. Nominal buoy 7.75 kg, reserve 210 N (3.77×), draft 2.53 in,
  freeboard 4.97 in, GM 9.56 in. The buoy is still substantially over-floated.
- **Single-wedge drop: no deformation.** John accepted this plus the FEA as sufficient and closed
  [SCO-71](https://linear.app/scout1/issue/SCO-71) and [SCO-111](https://linear.app/scout1/issue/SCO-111)
  ([drop test](../../../mechanical/test/wedge-drop-test-2026-09-25.md)).
- **The STEP files show the wedge bottom is 3.00 in tall, not 2 in.** Its foam cavity is 1.084 L,
  not 0.452 L. The freeboard model under-counts displacement by ~4 L, so the buoy floats higher
  than documented. The stack rebuild is [SCO-124](https://linear.app/scout1/issue/SCO-124).

- **Full-buoy assembly STEP committed:** [`mechanical/cad/full-buoy-assembly-v5.step`](../../../mechanical/cad/full-buoy-assembly-v5.step),
  the Fusion "DFM Assembly" model the FEA ran on.

## Still open

- Why the lean part is heavier than v4, and whether fewer walls would do given the FEA margins.
- Freeboard-model stack rebuild from the STEP geometry ([SCO-124](https://linear.app/scout1/issue/SCO-124)).
- Current v5 wedge and wedge-bottom drawings ([SCO-123](https://linear.app/scout1/issue/SCO-123)).
- The final 316 pad-eye FEA with LC7's moment applied correctly, on the custom PETG profile.

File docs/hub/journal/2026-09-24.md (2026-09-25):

# State Snapshot — 2026-09-24

> **Summary** — Dated snapshot of where S.C.O.U.T. stood on this day. Snapshots are append-only
> history; the always-current view is [`status.md`](../status.md).
>
> Part of the [Knowledge Hub](../README.md).

---

**Phase:** 1 — Subsystem Bring-Up (2026-09-07 – 2026-10-16)

## Where the project stands

The Prusa Mini is out as a wedge printer, and the larger printer is carrying the flotation
ring.

## Changed today

- **Prusa Mini prints failed, repeatedly.** John tried several times. Bed adhesion was poor,
  Z calibration was off, and there were other issues. No usable split half exists. See the
  [print log](../../../mechanical/test/wedge-bottom-split-print-2026-09-23.md#outcome-2026-09-24).
- **The larger printer printed wedges pretty well.** Filament had resistance in the PTFE
  tubes, and John fixed it.

## Still open

- Which larger printer, what exactly it printed, and how the PTFE fix was done. Whether that
  fix closes [SCO-114](https://linear.app/scout1/issue/SCO-114).
- Recalibrating the Prusa Mini (Z offset, bed adhesion) before it prints anything else.
- The split question on [SCO-111](https://linear.app/scout1/issue/SCO-111). The one-piece
  part stays the baseline.

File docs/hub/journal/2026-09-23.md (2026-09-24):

# State Snapshot — 2026-09-23

> **Summary** — Dated snapshot of where S.C.O.U.T. stood on this day. Snapshots are append-only
> history; the always-current view is [`status.md`](../status.md).
>
> Part of the [Knowledge Hub](../README.md).

---

**Phase:** 1 — Subsystem Bring-Up (2026-09-07 – 2026-10-16)

## Where the project stands

Printer capacity is now the constraint on the flotation ring. The EPIC lab's medium Prusa
failed, the large lab printer is still offline, and a full wedge bottom takes over a day to
print. Six are needed.

## Changed today

- **Medium Prusa failed, and is running on a workaround.** Its filament feeder had already been
  bypassed before today. John bypassed it again and put a rolling filament stand inside the
  enclosure. It appeared to work, but it isn't a proper repair.
- **Wedge bottom split into two parts** in CAD so each half fits and finishes on a Prusa Mini.
  It is one clean radial cut down the center, from the outer radius to the inner radius,
  giving two 30° halves with a flat butt joint. The joint method isn't recorded yet, and the
  halves' STEP isn't committed.
- **First half started on the Prusa Mini.** The bottom layers were poor: some nozzle drag, and
  filament-feed resistance at one point under-fed the bottom-layer infill. John left it running
  and will check it on 2026-09-24. See the
  [print log](../../../mechanical/test/wedge-bottom-split-print-2026-09-23.md).
- **Advisor meetings with Jes Kuczenski set tentatively for Tuesdays at 12:15.**
- **Hoeseok Yang (ECEN) recorded as a third faculty advisor** (from the 2026-09-22 team
  charter draft). README and CLAUDE.md updated.

## Still open

- Is the two-part wedge bottom permanent or only a print workaround? The seam would run
  through the waterline impact cap, a new leak path and weak line. The one-piece part stays
  the baseline until the team decides.
- The print result, the bottom-skin quality, and the half's printed mass.
- A proper repair of the medium Prusa's filament feed ([SCO-114](https://linear.app/scout1/issue/SCO-114)), and the large printer
  ([SCO-63](https://linear.app/scout1/issue/SCO-63)).
- Whether the Tuesday slot becomes standing.

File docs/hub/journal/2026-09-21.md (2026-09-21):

# State Snapshot — 2026-09-21

> **Summary** — Dated snapshot of where S.C.O.U.T. stood on this day. Snapshots are append-only
> history; the always-current view is [`status.md`](../status.md).
>
> Part of the [Knowledge Hub](../README.md).

---

**Phase:** 1 — Subsystem Bring-Up (2026-09-07 – 2026-10-16)

## Where the project stands

The first full-buoy assembly exists in Fusion. For the first time, every current part is in one
model, together with the mooring bracket and a candidate cable route. The bracket's mounting
method is now decided.

## Changed today

- **Mooring bracket mounting: through-bolts, nuts and an internal backing plate.** This replaces
  the heat-set-insert attachment modeled in the FEA. Through-bolts carry the ~810 N LC9 snap,
  which could pull inserts out of PETG. The backing plate spreads the nut load and closes the
  backing-plate gap flagged in the August design panel review. Each penetration is sealed with a
  bonded sealing washer or marine sealant, with epoxy as a secondary seal only. The bolt pattern
  follows the `3076T33` stand-in (4 × Ø1/4 in holes on a 1.250 × 1.125 in rectangle). The
  backing plate is 316 stainless, 2.50 × 2.25 × 0.125 in. Details in [facts.md](../facts.md).
- **Bracket attached and full buoy assembled in Fusion** from the updated parts.
- **Candidate cable routing modeled:** from the top-cap port, over the rim, down the outside of
  the float, under the bottom, then down the line to the sensor string. This is a concept only.
  See the [render](../../assets/diagrams/buoy-assembly-cable-routing-2026-09-21.png).
- **Hawaii site permitting:** John emailed Dr. Hannah Barkley (NOAA) to ask about test access
  at the buoy site she mentioned and whether an existing permit covers it. SCO-99 is closed, and
  the reply is tracked on SCO-113.

## Still open

- Chassis-bottom thickness at the bolt location, which sets the bolt length. It's about 4 in if
  the bolts pass through the full 76 mm section.
- The final 316 pad-eye part, which may change the bolt pattern, and an FEA re-run on the
  through-bolted interface (SCO-69, SCO-75).
- How the cable route handles abrasion, snagging, clamping and clearance from the mooring line.

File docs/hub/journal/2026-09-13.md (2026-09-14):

# State Snapshot — 2026-09-13

> **Summary** — Dated snapshot of where S.C.O.U.T. stood on this day. Snapshots are append-only
> history; the always-current view is [`status.md`](../status.md).
>
> Part of the [Knowledge Hub](../README.md).

---

**Phase:** 0 — Kickoff (2026-08-14 – 2026-09-20)

## Where the project stands

Four sensor-pod mechanical items today, each feeding the next: a sealing-method decision, a
formal packing analysis that found the current CAD undersized (catching a stale contradiction
between two engineering documents along the way), a resize of the top-cap O-ring seal that
followed directly from it, and — same day — the first physical part built off all of it.

## Changed today

- **Sensor-lead dry-chamber penetration: epoxy potting, not an O-ring.** Where the turbidity
  sensor's leads cross from the flood chamber into the dry chamber was never actually specified
  — the dry/flood split description and the O-ring manufacturing decision both predate an
  answer for this specific joint. John decided on epoxy potting, reasoning that an O-ring needs
  a smooth, round, dimensionally-precise mating surface that a cable simply isn't — a different
  failure mode than the printed O-ring that failed yesterday, but the same underlying lesson
  (seal method has to match the actual geometry being sealed). Requires an anti-wicking
  boss/sleeve, cable-jacket surface prep, and external strain relief so the pot isn't also
  doing strain-relief duty. Full write-up:
  [sensor-housing/README.md](../../mechanical/cad/sensor-housing/README.md#sensor-lead-dry-chamber-penetration--epoxy-potting-decided-2026-09-13).
- **First formal sensor-pod packing analysis — dry chamber is undersized.** Pulled the SEN0189's
  own manufacturer drawings (adapter board datasheet, plus a probe-body mechanical drawing
  fetched fresh from DFRobot's wiki and saved to `hardware/datasheets/`) and computed real
  chamber sizing for the first time. The probe's own **mounting ears** (44 mm diagonal span) —
  not the adapter board — govern the dry chamber's minimum diameter at **≥Ø52 mm**, bigger than
  the ~Ø31.5 mm bore already committed in the 2026-08-29 face-seal remodel. Also sized the
  probe-shaft penetration (Ø24 mm) and the flood chamber (≥Ø24 × 30 mm). Also ran a first
  closed-form wall-thickness check: **2.0 mm for the dry chamber** (no foam backing like the
  wedge has, so buckling governs — `SF` ≈4.7 at the 50.3 kPa / 5 m test pressure) vs. just
  **1.2–1.6 mm for the flood chamber**, which is water-filled both sides and never sees a net
  external load. Full analysis:
  [Sensor Pod Packing Budget](../../engineering/sensor-pod-packing-budget.md).
- **Caught and fixed a stale cross-document contradiction.** The
  [Electronics Housing Packing Budget](../../engineering/electronics-housing-packing-budget.md)
  (2026-08-25) had listed the SEN0189 adapter board as occupying volume in the *main* housing —
  silently disagreeing with the sensor-pod README's own "dry chamber holds the board"
  description the whole time. Confirmed with John: the board lives in the pod. Recomputed that
  document's three packing methods without it (Method 3's bare minimum: 68→63 mm,
  0.368→0.341 L) rather than leaving the wrong number standing now that it's been caught.
- **Top-cap O-ring resized to match — AS568-137 no longer fits.** John's layout for the dry
  chamber's top: a static face O-ring seal flared beyond the tube's own OD, same
  "fasteners outside the O-ring boundary" pattern as the electronics housing clamp. The
  originally-specified AS568-137's own ID (52.07 mm) is smaller than the new 56 mm tube OD it
  would need to wrap around. Sized a replacement candidate — **AS568-142** — targeting **25%
  squeeze / 75% gland fill**, checked against Parker's and Apple Rubber's published static-seal
  design guidance rather than just carried over from the electronics housing clamp's own
  22.9%/75%. Full derivation:
  [Sensor Pod Packing Budget §8](../../engineering/sensor-pod-packing-budget.md#8-top-cap-face-seal--resized-for-the-new-chamber-od-2026-09-13).
- **Dry-chamber body + lid modeled and printing — first part off today's numbers.** Same day.
  Body, lid, 3-bolt pattern, alignment spigot, and the probe-shaft penetration boss all
  modeled; flood chamber not yet. Confirmed the alignment spigot visible in John's renders is
  intentional (matches this pod's own precedent) on two conditions — loose diametral clearance
  and, more importantly, **axial clearance so the spigot never bottoms out before the flat
  sealing land does**, which would otherwise rob the O-ring of its designed squeeze. **First
  real weight: ~60 g.** Doesn't yet confirm exact dimensions against the day's recommendation
  (no callouts on a plain shaded render), the mounting-ear layout, or anything wet-tested. Full
  narrative:
  [sensor-housing/README.md § Dry-chamber body + lid](../../mechanical/cad/sensor-housing/README.md#dry-chamber-body--lid-modeled-and-printing--2026-09-13).

## Still blocking

Unchanged from [`status.md`](../status.md): the O-ring order ([SCO-106](https://linear.app/scout1/issue/SCO-106)),
LiFePO₄ charging path ([SCO-10](https://linear.app/scout1/issue/SCO-10)), hydrophone part number
([SCO-8](https://linear.app/scout1/issue/SCO-8)), SEN0189 non-inverting front end
([SCO-47](https://linear.app/scout1/issue/SCO-47)), parts arrival
([SCO-88](https://linear.app/scout1/issue/SCO-88)), and no shore Pi.

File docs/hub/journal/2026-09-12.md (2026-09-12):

# State Snapshot — 2026-09-12

> **Summary** — Dated snapshot of where S.C.O.U.T. stood on this day. Snapshots are append-only
> history; the always-current view is [`status.md`](../status.md).
>
> Part of the [Knowledge Hub](../README.md).

---

**Phase:** 0 — Kickoff (2026-08-14 – 2026-09-20)

## Where the project stands

One mechanical result today: the turbidity sensor-housing prototype, submerged for roughly a
week on a TPU-printed O-ring, was opened and found not waterproof.

## Changed today

- **Turbidity sensor housing — extended submersion failure.** John opened the housing after
  ~1 week submerged, sealed with a TPU-printed O-ring (a deliberate shortcut, not the specified
  AS568-137 ring). Not waterproof. Worth keeping the nuance rather than flattening it to a flat
  fail: the ring was, by his own assessment, very poor quality, and still kept out most water
  for most of the week — a slow-leak failure mode, not an immediate blow-out. Full record:
  [`mechanical/test/sensor-housing-tpu-oring-failure-2026-09-12.md`](../../mechanical/test/sensor-housing-tpu-oring-failure-2026-09-12.md).
- **Decision: no further housing submersion testing until a real, purchased O-ring is sourced.**
  John's reasoning — the printed ring's own inconsistency is the leading suspect for the leak,
  so continuing to test with printed rings would keep re-testing that same confound instead of
  the actual face-seal design. This is the second informal data point (after the
  [2026-08-24 bench test](../../mechanical/test/waterproofing-submersion-test-2026-08-24.md)) in
  the direction the original [O-ring manufacturing decision](../decision-log.md) (2026-08-17,
  off-the-shelf over printed) already assumed.
- **Corrected a stale claim in `facts.md`.** The housing-sealing-joint fact said "neither
  housing has been submersion-tested to this design" — no longer true for the sensor pod, which
  has now been tested (informally, with the wrong ring, and it failed). Updated in place rather
  than left to drift, per Standing Rule 1.

## Raised today

- [SCO-91](https://linear.app/scout1/issue/SCO-91) (validate the remodelled face seal) moved
  `In Progress` → `Blocked`, blocked by [SCO-106](https://linear.app/scout1/issue/SCO-106)
  (choose the elastomer and order the real rings) — it was stuck on a parts dependency, not
  actually being worked, so it shouldn't have looked like it was.
- [SCO-106](https://linear.app/scout1/issue/SCO-106) is now the pacing item for all further
  sensor-housing waterproofing work — the sole clear next step is ordering the AS568-137 (and
  AS568-043) rings.

## Still blocking

Unchanged from [`status.md`](../status.md), plus the new O-ring dependency above: LiFePO₄
charging path ([SCO-10](https://linear.app/scout1/issue/SCO-10)), hydrophone part number
([SCO-8](https://linear.app/scout1/issue/SCO-8)), SEN0189 non-inverting front end
([SCO-47](https://linear.app/scout1/issue/SCO-47)), parts arrival
([SCO-88](https://linear.app/scout1/issue/SCO-88)), and no shore Pi.

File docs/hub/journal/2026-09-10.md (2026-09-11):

# State Snapshot — 2026-09-10

> **Summary** — Dated snapshot of where S.C.O.U.T. stood on this day. Snapshots are append-only
> history; the always-current view is [`status.md`](../status.md).
>
> Part of the [Knowledge Hub](../README.md).

---

**Phase:** 0 — Kickoff (2026-08-14 – 2026-09-20)

## Where the project stands

Two stretches of work on the same day. The morning was a repo-wide consistency audit and the
[Integration Runbook](../../engineering/integration-runbook.md); writing that runbook is what
surfaced the software gaps the hardware blockers had been hiding, and the rest of the day closed
five of them.

Software is in good shape and hardware has not arrived. Every subsystem that can be verified
without a board is verified; nothing has met a real sensor, radio, or water.

## Changed today

- **Repo-wide consistency audit.** The settled 30-byte packet size was propagated to eleven
  places still claiming 82 bytes — including the public website's spec table and CLAUDE.md's own
  Standing Rule 2. 59 broken links repaired (all depth errors, no missing files) and 17 dead
  anchors fixed. `facts.md` was correct throughout and was not touched.
- **Integration runbook written** ([Integration Runbook](../../engineering/integration-runbook.md)) —
  the full bench-to-field procedure: toolchain, what programs what, and ten staged bring-up steps
  each with a PASS gate. Written to be executed by a Claude session with a human doing only the
  physical work. Stage 0 is verified and runnable today; Stages 1–10 are specified but unrun,
  because no hardware exists.

### The shore station became a real deployment target (CSEN)

Three separate problems, one underlying cause: nobody had walked the path from *a packet
arriving* to *a number on the public dashboard*. Each piece existed; none of them connected.

- **There was no publish path at all.** `shore/data/` is gitignored, so received CSVs could
  never have been committed. And the Pages workflow regenerated 30 days of simulated telemetry
  on an hourly cron and rebuilt the site from it unconditionally — so even a force-added real
  file would have been overwritten within the hour and relabelled *"not a live deployment"*.
  No error, no failed check, no diff. The dashboard would have kept looking healthy while
  showing nothing real. Received data now lands in a tracked `shore/data-live/`, the simulator
  writes only to the gitignored scratch directory, and the choice between them is made in
  tested code rather than in workflow YAML.
- **There was no service.** The receiver was a script someone ran by hand; a reboot or power
  cut ended reception silently, and because the buoy transmits blind neither end would have
  raised an alarm. It now runs under systemd with `Restart=always`, a clean SIGTERM stop, and a
  capped widening backoff so a dead radio does not pin the Pi's CPU.
- **The loop cannot use `link.pending`.** A real SX1276 cannot report a queue depth —
  `Rfm9xLink.pending` returns 0 and says so. A loop built on it passes every test against the
  mock and then sits idle forever against real sky. The service watches `stats.received`
  instead, and there is a test that pins exactly that.

### A contradiction that had been sitting in the canonical facts (cross-discipline)

[`facts.md`](../facts.md) asserted that the internal SoH temp/humidity sensor **"is fitted"**.
[Data Schema](../../engineering/data-schema.md) said those columns were **"not in the v1 BOM"**
and listed the sensor as an open question. The firmware had no code for it. All three had been
true-sounding and mutually incompatible for weeks.

The underlying decision was never in doubt —
[ADR-0005](../../decisions/0005-v1-sensing-payload.md) settled that a sensor *is added*, and its
value is real: humidity near zero in a sealed bay means a rise is a leak, the earliest warning
for the failure mode that ends a deployment. What never happened is everything after the
decision: no part number, no BOM line, no driver, no `schema_version` bump.

Nothing was reconciled by picking a side. `facts.md` now says **decided, not yet fitted**, the
schema points at the ADR instead of reading as undecided, and the actual open item — which part,
and does it make Rev A — is filed with an owner in
[`open-questions.md`](../research/open-questions.md). The
[decision log](../decision-log.md) row from 2026-08-17 was left exactly as written: it records
what was decided that day, which is still accurate.

### Two gaps closed that turned out smaller than first reported (CSEN)

Both had been described more alarmingly than the evidence supported, and checking narrowed them.

- **The acoustic stack on ARM** was called "an untested assumption". Querying PyPI turned it
  into a settled provisioning rule: **aarch64 is clean** — every pinned package and compiled
  transitive dependency ships an ARM wheel — while **armv7l has no wheel for nine of them**, so
  pip would build SciPy from source on a board that usually runs out of RAM trying. So the fix
  is one line in the provisioning docs (use the 64-bit image), not a porting effort. The check
  is a script, so it can be re-run when the pins change rather than re-argued.
- **"No backfill path off the SD card"** overstated it. `load_dir` already reads any directory
  of CSVs, so a card could always be analysed. What was missing was *merging* it with the shore
  record — and since the card is the richer copy (a 30-byte packet cannot carry `turbidity_v`,
  `turbidity_ntu`, or the audio filename), the merge also fills columns shore never had.
  Against a simulated 9-hour outage: **62.5% → 100% completeness, 1 gap → 0, and 0 → 48 rows
  with `turbidity_v`.**

### Lean wedge bottom re-modelled (GENG)

John printed the first wedge bottom off the v4-era geometry and stopped it — a non-structural
impact/waterline cap was on track to waste far more filament than it needs. He re-modelled a
**lean** version in Onshape: a shallow 60° tray (cavity floor out to ~R6.13/R6.25 in, walls
0.120 in outer / 0.077 in sides, floor ~0.114 in; **height and R9.000 in outer radius unchanged
from v4**) with **small registration tabs on the top rim** so the wedge shell seats firmly over
it. The smaller part is
printing successfully. Drawing committed at
[`chassis-floatation-bolted-v5-wedge-bottom.pdf`](../../../mechanical/cad/floatation/chassis-floatation-bolted-v5-wedge-bottom.pdf);
full narrative in
[floatation/README.md § Lean wedge bottom (v5)](../../../mechanical/cad/floatation/README.md#lean-wedge-bottom-v5--2026-09-10).

### Public website drawings brought current

The buoy CAD gallery on the home and technology pages had been showing the superseded v1–v9
three-part flotation concept (`floatation-top/shell/bottom.png`) since it first went live —
dropped in favor of the bolted-wedge design on 2026-08-17, but nobody swapped the site's
pictures. Re-rendered five drawings from the actual current design (v4 wedge, wedge cap,
chassis, chassis cap; the new lean v5 wedge bottom) and updated
[`drawings.py`](../../../analytics/telemetry/site/drawings.py) to reference them.

## Raised today

- **Wedge-bottom propagation debt.** The lean re-model above supersedes the v4 wedge bottom
  (181.21 g, 0.452 L cavity, thick gyroid cap) that the
  [mass budget](../../engineering/buoy-structural/mass-and-buoyancy-budget.md),
  [freeboard model](../../engineering/buoy-structural/buoy-mass-displacement-and-freeboard-model.md),
  [stability](../../engineering/buoy-structural/stability-analysis.md), and
  [impact](../../engineering/buoy-structural/impact-survivability-analysis.md) analyses still
  use. Not silently reconciled — each doc now carries a note — but a STEP export, a re-slice
  for real weight, a print-settings re-spec, and a re-check of impact Scenario C are owed
  before those numbers are trustworthy for v5. Filed as [SCO-111](https://linear.app/scout1/issue/SCO-111).

- **🔴 New blocker: the Rev A pin map contradicts the firmware.** The schematic annotates
  `TEMP_DATA = Feather D5`; `config.h` has `PIN_ONEWIRE 12` and needs `D5` for the RTC wake
  interrupt. Flashed as-is, the DS18B20 never reads *and* the buoy cannot wake from standby.
  The Adalogger's PCF8523 `INT1` also needs a solder jumper that no assembly step calls for.

  This is the same class as the `PIN_TURBIDITY` A0→A1 error caught in
  [SCO-85](https://linear.app/scout1/issue/SCO-85) — that one was found, this one was not.
  Recorded as an open fact and a pending decision; **Isabella (ECE) owns the call**. Both
  resolutions are written up; the runbook holds a blocking gate until one is applied.

Session: writing the [Integration Runbook](../../engineering/integration-runbook.md) surfaced a
set of software gaps that the hardware blockers had been hiding. Three of them closed today, on
top of the RTC and radio work earlier in the day.

## Still blocking

Unchanged, plus the new pin-map gate: LiFePO₄ charging path
([SCO-10](https://linear.app/scout1/issue/SCO-10)), hydrophone part number
([SCO-8](https://linear.app/scout1/issue/SCO-8)), SEN0189 non-inverting front end
([SCO-47](https://linear.app/scout1/issue/SCO-47)), parts arrival
([SCO-88](https://linear.app/scout1/issue/SCO-88)), and no shore Pi.

Unchanged from [`status.md`](../status.md). Nothing closed today was blocked on hardware, which
was the point of picking these three — the parts blocker ([SCO-88](https://linear.app/scout1/issue/SCO-88))
still gates driver validation and the shore radio bring-up.

The one new thing worth watching: `shore/data-live/` is now the contract between the Pi and the
published site. If the Pi ever writes somewhere else, the dashboard will silently keep showing
sample data — the same failure this session removed, reintroduced by configuration.

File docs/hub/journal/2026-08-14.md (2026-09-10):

# State Snapshot — 2026-08-14

> **Summary** — Dated snapshot of where S.C.O.U.T. stood on this day. Snapshots are append-only
> history; the always-current view is [`status.md`](../status.md).
>
> Part of the [Knowledge Hub](../README.md).

---

**Phase:** 0 — Kickoff (2026-08-14 – 2026-09-04)

## Where the project stands

The August 2026 documentation audit is essentially closed. Five cross-document contradictions
were resolved through [ADR-0001](../../decisions/0001-mcu-and-radio-selection.md) (MCU/radio),
[ADR-0003](../../decisions/0003-single-point-sensing.md) (single-point sensing), and a batch of
reconciliation PRs (#1–#8). The build platform is settled, so firmware is unblocked for the
first time. The acoustic pipeline is the one fully working subsystem.

Today the **Knowledge Hub** was established to keep the project from drifting back into that
state: canonical facts, a decision ledger, this status journal, and a research library.

## Changed since project start

- Repo restructured into the multi-discipline layout.
- `CLAUDE.md` + `CONVENTIONS.md` adopted as the operating contract.
- Timeline re-baselined to Aug 2026 – May 2027.
- S.C.O.U.T. reframed as a nearshore monitoring **platform**.
- CSV data schema v1 defined (firmware ↔ analytics contract).
- Knowledge Hub created (this snapshot is its first journal entry).
- Flotation (top/shell/bottom) and turbidity-sensor housing drawings imported into
  `mechanical/cad/` (PDF exports; native + STEP still to follow).

## Software track (CSEN)

The environmental-telemetry analytics gained **multi-buoy (fleet) support**. The backend —
group records by `buoy_id`, analyse each buoy in isolation with its own MMM, never blended —
merged to `main` ([`analytics/telemetry/fleet.py`](../../../analytics/telemetry/fleet.py),
PR #25). The **fleet dashboard UI** (a `/fleet/` overview: a rollup strip plus a
severity-sorted grid of buoy tiles, each drilling into that buoy's full dashboard) is built on
the web-redesign branch (open PR #27,
[`fleet_web.py`](../../../analytics/telemetry/fleet_web.py)) and lands on `main` when #27 merges.
When it does, the public dashboard becomes multi-buoy — see
[Live Dashboard](../../engineering/live-dashboard.md) and the new
[environmental-telemetry facts](../facts.md#analytics-environmental-telemetry).

## Blocking now

1. LiFePO₄ charging path — [ADR-0002](../../decisions/0002-lifepo4-charging-path.md) still open.
2. Hydrophone part number (H2a-XLR vs H2dM) — needs a Linear issue.
3. Dissolved oxygen inclusion — needs a Linear issue.

## Next

- Close ADR-0002 and the two open sensor questions to fully clear Phase 0.
- Begin firmware Phase 1 (DS18B20 read, RTC wake, CSV append) against the SAMD21 core.
- Create the private `library-restricted/` submodule and start filling the research library.

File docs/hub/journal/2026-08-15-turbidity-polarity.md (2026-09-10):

# State Snapshot — 2026-08-15 (turbidity polarity)

> **Summary** — Dated snapshot of where S.C.O.U.T. stood on this day. Snapshots are append-only
> history; the always-current view is [`status.md`](../status.md). Third entry for 2026-08-15,
> after the telemetry drift work and the firmware link work.
>
> Part of the [Knowledge Hub](../README.md).

---

**Phase:** 0 — Kickoff (2026-08-14 – 2026-09-04)

## Where the project stands

Phase 0's three hardware blockers are unchanged. This entry closes the loop on the polarity
question raised earlier today, which turned out to be larger than it looked.

## Resolved today

**A higher `turbidity_adc` count means CLEARER water.** The DFRobot datasheet settles it
outright — *"Analog Signal Output, the output value will decrease when in liquids with a high
turbidity"* — with clear water (< 0.5 NTU) at ≈ 4.1 V. The SEN0189 measures transmittance, so
particles blocking light lower its output, and the firmware logs raw `analogRead` with no
inversion. No bench session was needed to settle the direction; the datasheet is explicit.

**Three modules had it backwards**, not one:

1. `turbidity.py` flagged **positive** excursions as "dirtier water" — it was reporting each
   day's *clearest* readings as sediment plumes, on a public dashboard.
2. `drift.py` took the **10th percentile** as the day's "clean-water floor". With the real
   polarity that is the *dirtiest* reading of the day — precisely the runoff events the method
   exists to exclude. Now the 90th percentile, renamed to "clean-water reading".
3. The shore simulator generated turbidity events as an ADC **rise** (500 → 900), so the sample
   data feeding the public dashboard was physically inverted too. Now 3300 → 2000.

Worth recording honestly: yesterday's note claimed the drift screen was "sign-agnostic and
therefore safe either way." That was right about the *detection* — a monotonic march is caught
in both directions — but wrong overall, because the **percentile** that feeds it was directional
and sat on the wrong tail. Sign-agnostic detection over the wrong input is still wrong.

## Raised today

**A constraint the ECE track needs.** The SEN0189 swings to 4.5 V and the SAMD21 ADC tops out
at 3.3 V, so a level-shifting front end sits between them — still undesigned under
[ADR-0002](../../decisions/0002-lifepo4-charging-path.md). It **must be non-inverting** (a
divider or buffer, not an inverting amplifier), or this convention and every analytic built on
it silently flip. Recorded in [`facts.md`](../facts.md) and
[Data Schema](../../engineering/data-schema.md).

## Still blocking

Unchanged — all three are ECE/hardware decisions:

1. LiFePO₄ charging path ([SCO-10](https://linear.app/scout1/issue/SCO-10))
2. Hydrophone part number ([SCO-8](https://linear.app/scout1/issue/SCO-8))
3. Dissolved-oxygen inclusion ([SCO-11](https://linear.app/scout1/issue/SCO-11))

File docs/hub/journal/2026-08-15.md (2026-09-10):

# State Snapshot — 2026-08-15

> **Summary** — Dated snapshot of where S.C.O.U.T. stood on this day. Snapshots are append-only
> history; the always-current view is [`status.md`](../status.md).
>
> Part of the [Knowledge Hub](../README.md).

---

**Phase:** 0 — Kickoff (2026-08-14 – 2026-09-04)

## Where the project stands

Unchanged at the system level: Phase 0's three blockers are still open and all of them are
hardware calls. The CSEN track's two High-priority items — real LoRa receive on the shore
station ([SCO-24](https://linear.app/scout1/issue/SCO-24)) and on-hardware SAMD21 driver
validation ([SCO-25](https://linear.app/scout1/issue/SCO-25)) — remain blocked behind the
LiFePO₄ charging path ([ADR-0002](../../decisions/0002-lifepo4-charging-path.md),
[SCO-10](https://linear.app/scout1/issue/SCO-10)), so today's work was the software-only item
that needed no hardware.

## Changed today

- **Biofouling drift detection landed** ([SCO-16](https://linear.app/scout1/issue/SCO-16)).
  The telemetry QC now runs QARTOD flat-line and rate-of-change tests per channel, and a new
  `drift.py` screens the turbidity channel for the slow monotonic baseline march that fouling
  produces — cross-checked against the non-optical temperature channel per `manov-2004`.
  Verified end to end: on 30 days of shore-simulator data with synthetic fouling injected, the
  existing Mann-Kendall turbidity trend reports `increasing (p=0.0)` and is fooled, while the
  new screen correctly attributes it to the instrument.
- **Rate-of-change is temperature-only.** On turbidity it flagged ~12% of the shore sample —
  runoff and resuspension are genuinely abrupt, so the test fires on weather rather than faults,
  and `turbidity.py` already detects those excursions with a robust median/MAD statistic.

## Raised today

- **The SEN0189's ADC→turbidity polarity is unresolved and possibly inverted in code.**
  `turbidity.py` treats a rising `turbidity_adc` as dirtier water, but the DFRobot SEN0189's
  output voltage *falls* as turbidity rises and the firmware logs `analogRead` with no
  inversion — so the event detector may be flagging the wrong tail. Recorded in
  [`decision-log.md`](../decision-log.md) as pending and in
  [`open-questions.md`](../research/open-questions.md), and staged as
  [linear-backlog D1](../linear-backlog.md#d-staged--now-all-filed) — ⏳ **not yet in Linear**,
  as this session had no `scout1` access. The formazin ladder in
  [SCO-12](https://linear.app/scout1/issue/SCO-12) settles it directly on the bench. The new
  drift screen is deliberately sign-agnostic so it stays correct either way.

## Still blocking

Unchanged from 2026-08-14 — all three are ECE/hardware decisions:

1. LiFePO₄ charging path ([SCO-10](https://linear.app/scout1/issue/SCO-10))
2. Hydrophone part number ([SCO-8](https://linear.app/scout1/issue/SCO-8))
3. Dissolved-oxygen inclusion ([SCO-11](https://linear.app/scout1/issue/SCO-11))

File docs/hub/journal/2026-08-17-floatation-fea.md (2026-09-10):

# State Snapshot — 2026-08-17 (Floatation & FEA)

> **Summary** — Second dated snapshot for 2026-08-17 — see also
> [2026-08-17.md](2026-08-17.md) (O-rings, mooring approach) and the SCOUT Weekly entry in
> [meeting-notes.md](../../planning/meeting-notes.md). Snapshots are append-only history; the
> always-current view is [`status.md`](../status.md).
>
> Part of the [Knowledge Hub](../README.md).

---

**Phase:** 0 — Kickoff (2026-08-14 – 2026-09-04)

## Where the project stands

Mechanical design (John Ryan, `geng`) chose the final floatation family — the bolted wedge
variant with bottom caps — and ran the first structural FEA pass on it. This session also
corrects a same-day meeting summary that predated the bottom caps and overstated a provisional
FEA pass/fail criterion as an established target.

## Changed today

- **Floatation family chosen**: bolted wedge variant (heat-set inserts + bolts, no snap/keyhole
  locking) over the snap/keyhole Master V3 and Outer Octagon. New bottom caps under each wedge
  (gyroid infill, many wall layers) for impact protection; foam fill and surfboard-stringer-
  inspired radial webs carry over. Chosen after this morning's print test found integrating the
  bottom caps into the snap/keyhole body broke its previously-working keyhole slide-in function
  — see [mechanical/cad/floatation/README.md](../../../mechanical/cad/floatation/README.md#bolted-variant-chosen--2026-08-17).
- **First FEA pass**: Autodesk Fusion static-stress study, 300 N side load on the floatation +
  bottom caps, ABS material properties. Minimum safety factor 25.4 against an SF≥4 check used
  only for this study — not yet a validated target. Full record:
  [mechanical/test/fea-floatation-side-load-2026-08-17.md](../../../mechanical/test/fea-floatation-side-load-2026-08-17.md).
- **Corrected a same-day record**: the 2026-08-17 SCOUT Weekly meeting summary in
  [decision-log.md](../decision-log.md) and [meeting-notes.md](../../planning/meeting-notes.md)
  recorded the bolted+foam choice but predates the bottom caps and stated the safety-factor
  figure without the provisional-target caveat. `decision-log.md`, `facts.md`, and
  `design-notes.md` now carry the complete, corrected version from the mechanical lead
  directly; the historical meeting-note entry is left as-is (an accurate record of what was
  reported at the meeting itself).
- **Two new Linear issues filed**: [SCO-68](https://linear.app/scout1/issue/SCO-68) (chassis
  top section — sealing + service-access port, explicitly requested this session) and
  [SCO-69](https://linear.app/scout1/issue/SCO-69) (mooring/sensor-string attachment hardware —
  leading candidate is a stainless U-bolt + mounting plate, not yet designed).

## Still blocking

1. LiFePO₄ charging path ([SCO-10](https://linear.app/scout1/issue/SCO-10))
2. Hydrophone part number ([SCO-8](https://linear.app/scout1/issue/SCO-8))
3. Housing dimensions ([SCO-49](https://linear.app/scout1/issue/SCO-49)) — now also blocks the
   remaining floatation acceptance criteria on [SCO-48](https://linear.app/scout1/issue/SCO-48)
   and the new chassis top-section task ([SCO-68](https://linear.app/scout1/issue/SCO-68))
4. Print material — PETG default, ABS/ASA under evaluation
   ([SCO-64](https://linear.app/scout1/issue/SCO-64))

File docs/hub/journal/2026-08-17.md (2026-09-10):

# State Snapshot — 2026-08-17

> **Summary** — Dated snapshot of where S.C.O.U.T. stood on this day. Snapshots are append-only
> history; the always-current view is [`status.md`](../status.md).
>
> Part of the [Knowledge Hub](../README.md).

---

**Phase:** 0 — Kickoff (2026-08-14 – 2026-09-04)

## Where the project stands

Mechanical design (John Ryan, `geng`) closed two of the open decisions that had been sitting
under "Mechanical design" in [`status.md`](../status.md): O-ring manufacturing method and the
reef-safe anchoring/mooring approach. Both were made live in session rather than left for a
future PR.

## Changed today

- **O-ring manufacturing method decided** ([SCO-55](https://linear.app/scout1/issue/SCO-55)):
  purchased off-the-shelf standard rings, not the TPU-printed experiment or a batch-cast
  injection mold from PR #60. Printed parts are porous along layer lines — a
  waterproofing-critical risk at the 5 m pressure target — and standard rings have
  well-characterized long-duration compression-set behavior an untested printed part doesn't.
  Provisional: revisit if standard AS568 sizes don't fit the housing tolerances.
- **Reef-safe anchoring/mooring approach decided**
  ([ADR-0004](../../decisions/0004-reef-safe-anchoring-and-mooring.md),
  [SCO-17](https://linear.app/scout1/issue/SCO-17)): marked sites (existing pile/mooring)
  connect directly via line; unmarked sites get a single **mushroom anchor**, chosen because it
  sets by vertical embedment rather than dragging to bite, so deployment itself can't scrape
  adjacent coral. Sited adjacent to (never on) coral with swing clearance. Synthetic marine
  rope by default, chain in high-turbulence sites.

## Still blocking

Unchanged — all three are ECE/hardware decisions:

1. LiFePO₄ charging path ([SCO-10](https://linear.app/scout1/issue/SCO-10))
2. Hydrophone part number ([SCO-8](https://linear.app/scout1/issue/SCO-8))
3. Dissolved-oxygen inclusion ([SCO-11](https://linear.app/scout1/issue/SCO-11))

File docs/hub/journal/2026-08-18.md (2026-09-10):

# State Snapshot — 2026-08-18

> **Summary** — Dated snapshot of where S.C.O.U.T. stood on this day. Snapshots are append-only
> history; the always-current view is [`status.md`](../status.md).
>
> Part of the [Knowledge Hub](../README.md).

---

**Phase:** 0 — Kickoff (2026-08-14 – 2026-09-04)

## Where the project stands

Mechanical design (John Ryan, `geng`) closed the biofouling mitigation decision and made
progress on floatation: a physical fit-test print, a weight datapoint, and a pivot in what the
structural design is being validated against.

## Changed today

- **Biofouling mitigation decided** ([SCO-15](https://linear.app/scout1/issue/SCO-15)):
  antifouling coating (over copper mesh and mechanical wipers), specific product **Sea Hawk
  Smart Solution** (copper-free, Econea biocide) — chosen over copper-based general-retailer
  options, which conflict with the reef-safe principle set for the mooring
  ([ADR-0004](../../decisions/0004-reef-safe-anchoring-and-mooring.md)).
- **Bolted-wedge cross-section fit test printed** — a single row of the bolt pattern (not a
  full wedge) sliced to confirm the bolted fit against the chassis without spending filament on
  a full-height piece. Fit confirmed. Slicer weight estimate: **~300 g per full-size wedge**,
  now logged in [`facts.md`](../facts.md#mechanical--deployment) as the input the
  [SCO-48](https://linear.app/scout1/issue/SCO-48) buoyancy check needs.
- **Floatation validation target pivots to impact survivability.** The 2026-08-17 FEA pass (min
  safety factor 25.4 against a provisional SF≥4 check) is now read as over-engineered relative
  to the project's cost target. Future testing targets impact/boat-strike survivability at
  controlled cost instead — FEA impact/drop-load simulation plus bench impact tests on printed
  samples, tracked as [SCO-71](https://linear.app/scout1/issue/SCO-71). Full narrative:
  [`mechanical/cad/floatation/README.md`](../../../mechanical/cad/floatation/README.md#cross-section-fit-test-print-and-a-validation-target-pivot--2026-08-18).
- **New open question: propeller-resistant mooring/tether line**
  ([SCO-72](https://linear.app/scout1/issue/SCO-72)) — a boat crossing the line should ideally
  foul the propeller rather than cut the line and lose the buoy adrift. ADR-0004 already scoped
  final line material/diameter as a routine sizing decision; this adds a concrete criterion to
  weigh against it.

## Still blocking

Both are ECE/hardware decisions — dissolved-oxygen inclusion, the third item carried in the
2026-08-17 snapshot, closed that same day ([ADR-0005](../../decisions/0005-v1-sensing-payload.md),
excluded from V1):

1. LiFePO₄ charging path ([SCO-10](https://linear.app/scout1/issue/SCO-10))
2. Hydrophone part number ([SCO-8](https://linear.app/scout1/issue/SCO-8))

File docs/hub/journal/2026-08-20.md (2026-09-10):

# State Snapshot — 2026-08-20

> **Summary** — Dated snapshot of where S.C.O.U.T. stood on this day. Snapshots are append-only
> history; the always-current view is [`status.md`](../status.md).
>
> Part of the [Knowledge Hub](../README.md).

---

**Phase:** 0 — Kickoff (2026-08-14 – 2026-09-04)

## Where the project stands

Mechanical design (John Ryan, `geng`) added two new parts to the bolted wedge floatation
assembly: a chassis cap and a wedge cap, modeled 2026-08-19. This is a first pass at the
[SCO-53](https://linear.app/scout1/issue/SCO-53) cable-gland cap revision — cable routing and
the cap's fit against the chassis are still open.

## Changed today

- **Chassis cap + wedge cap added to the bolted wedge assembly.** Wedge cap press-fits and
  epoxies into each wedge, sealing the foam cavity before fill. Chassis cap covers the central
  chassis cylinder and extends slightly over each wedge top — whether its OD is larger than or
  flush with the chassis is not yet decided. Planned build sequence: epoxy the wedge cap in,
  then inject foam — the gap under the chassis cap gives expanding foam somewhere to overflow,
  trimmed flush afterward (the same role flash plays in injection molding). Five new STEP files
  committed to `mechanical/cad/floatation/`, including the first CAD for the bottom cap under
  each wedge described in the 2026-08-17 snapshot but not modeled until now. Full narrative:
  [`mechanical/cad/floatation/README.md`](../../../mechanical/cad/floatation/README.md#chassis-cap--wedge-cap-added--2026-08-20).
- **Two new open questions on the same design:**
  1. **Cable exit routing** — a channel down the side of one wedge, or a direct through-hole in
     the middle of one wedge, for sensor/harness cables to exit through the chassis cap.
  2. **Solar mount attachment** — likely a direct screw-top mount to the chassis cap with
     clearance spacers, not yet modeled against the existing solar-mount bracket
     ([SCO-54](https://linear.app/scout1/issue/SCO-54)).

## Still blocking

1. LiFePO₄ charging path ([SCO-10](https://linear.app/scout1/issue/SCO-10))
2. Hydrophone part number ([SCO-8](https://linear.app/scout1/issue/SCO-8))
3. Housing dimensions ([SCO-49](https://linear.app/scout1/issue/SCO-49)) — blocks both the
   buoyancy check on [SCO-48](https://linear.app/scout1/issue/SCO-48) and gland placement on
   [SCO-53](https://linear.app/scout1/issue/SCO-53)

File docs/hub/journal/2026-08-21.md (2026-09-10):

# State Snapshot — 2026-08-21

> **Summary** — Dated snapshot of where S.C.O.U.T. stood on this day. Snapshots are append-only
> history; the always-current view is [`status.md`](../status.md).
>
> Part of the [Knowledge Hub](../README.md).

---

**Phase:** 0 — Kickoff (2026-08-14 – 2026-09-04)

## Where the project stands

John Ryan ran a simulated multidisciplinary design panel review of the buoy's flotation,
structural chassis, mooring, sealing, manufacturing, and field-reliability architecture, using
the current CAD (bolted wedge floatation + central chassis, chassis cap + wedge cap as of
2026-08-20). Panel verdict: proceed to detailed design, no concept redesign. Full write-up:
[Buoy Preliminary Design Panel Review](../../engineering/reviews/buoy-preliminary-design-panel-review-2026-08.md).

## Changed today

- **Architecture confirmed, not changed.** No reviewer identified a reason to abandon the
  central-chassis / six-foam-wedge concept (overall architecture rated 8.0/10, flotation
  philosophy 9.0/10, serviceability 8.5/10).
- **Two priority gaps identified before a structural design freeze:**
  1. The U-bolt/backing-plate/chassis mooring load path — rated the single critical
     single-point failure (complete buoy loss if it fails) and not yet engineered beyond
     "stainless U-bolt through the chassis bottom."
  2. Chassis print structure (5.0/10, "incomplete rather than fundamentally poor") — the
     currently-considered 3–4 perimeters / ~15% gyroid infill is a generic enclosure recipe,
     not a load-path-engineered marine structure; 1.2–1.6 mm of actual shell around the U-bolt
     attachment was flagged as a concern.
- **A concrete lid-seal defect flagged:** the current top-lid fasteners sit inside the O-ring
  sealing boundary, so every fastener is a potential leak path into the dry volume. Preferred
  fix is moving fasteners outside the boundary while CAD changes are still cheap.
- **14 prioritized follow-up actions triaged against Linear.** 5 overlapped existing tickets
  and were enriched in place rather than duplicated: [SCO-69](https://linear.app/scout1/issue/SCO-69)
  (U-bolt/backing-plate load path — priority raised Medium→High), [SCO-73](https://linear.app/scout1/issue/SCO-73)
  (added the fatigue/cyclic-loading criterion), [SCO-68](https://linear.app/scout1/issue/SCO-68)
  (added the O-ring-boundary fastener fix + gland-sizing criteria), and [SCO-53](https://linear.app/scout1/issue/SCO-53)/
  [SCO-48](https://linear.app/scout1/issue/SCO-48) (cross-referenced via comment, no changes
  needed). 9 had no existing home and were filed as new issues: [SCO-74](https://linear.app/scout1/issue/SCO-74)
  (mass/displacement budget), [SCO-75](https://linear.app/scout1/issue/SCO-75) (chassis print
  structure), [SCO-76](https://linear.app/scout1/issue/SCO-76) (foam-fill trials),
  [SCO-77](https://linear.app/scout1/issue/SCO-77) (fastener/anti-loosening strategy),
  [SCO-78](https://linear.app/scout1/issue/SCO-78) (coating durability),
  [SCO-79](https://linear.app/scout1/issue/SCO-79) (biofouling/field-handling features),
  [SCO-80](https://linear.app/scout1/issue/SCO-80) (stability/CG-CB/ballast),
  [SCO-81](https://linear.app/scout1/issue/SCO-81) (buoyancy-under-failure verification),
  [SCO-82](https://linear.app/scout1/issue/SCO-82) (integrated proof/tilt/waterproof tests,
  the final deployment gate).
- Raw review PDF and its Markdown transcription committed to a new
  [`docs/engineering/reviews/`](../../engineering/reviews/README.md) folder — a new, small
  convention for pairing a delivered review PDF with a diffable write-up, since
  CONVENTIONS.md's "Documents → Markdown" rule didn't have an existing slot for this.
- **Chassis/wedge print structure (wall count + infill %) set for construction.** The review
  flagged the chassis's generic 3–4 wall / ~15% gyroid recipe as inadequate but gave no
  numbers; researched FDM/PETG structural-print literature to fill the gap and logged the
  result as a provisional decision: wedge family unchanged, chassis to 6 walls / 25–30%
  gyroid (8–10+ walls / 100% local solid at the U-bolt boss), chassis cap provisionally
  matching the chassis. 8 new sources added to [research/sources.md](../research/sources.md)
  under three new bibliography sections. Explicitly provisional pending
  [SCO-73](https://linear.app/scout1/issue/SCO-73)'s FEA results.

## Still blocking

1. LiFePO₄ charging path ([SCO-10](https://linear.app/scout1/issue/SCO-10))
2. Hydrophone part number ([SCO-8](https://linear.app/scout1/issue/SCO-8))
3. Housing dimensions ([SCO-49](https://linear.app/scout1/issue/SCO-49)) — blocks both the
   buoyancy check on [SCO-48](https://linear.app/scout1/issue/SCO-48) and gland placement on
   [SCO-53](https://linear.app/scout1/issue/SCO-53)
4. Mooring U-bolt/backing-plate load-path engineering ([SCO-69](https://linear.app/scout1/issue/SCO-69),
   priority raised to High today) — the most consequential single-point failure identified today

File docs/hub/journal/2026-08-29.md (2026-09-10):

# State Snapshot — 2026-08-29

> **Summary** — Dated snapshot of where S.C.O.U.T. stood on this day. Snapshots are append-only
> history; the always-current view is [`status.md`](../status.md).
>
> Part of the [Knowledge Hub](../README.md).

---

**Phase:** 0 — Kickoff (2026-08-14 – 2026-09-04)

## Where the project stands

John Ryan produced the whole-buoy mass, displacement, and freeboard model
([SCO-74](https://linear.app/scout1/issue/SCO-74)) and, from its geometry plus the existing
[structural load framework](../../engineering/buoy-structural/structural-load-framework.md),
a ready-to-run Fusion FEA load set ([SCO-73](https://linear.app/scout1/issue/SCO-73), partial —
the environmental design set is proposed, not signed off). Built and checked with a multi-agent
pass (3 independent derivations → reconciliation → 2 adversarial math verifiers → 2 auditors).

## Changed today

- **Whole-buoy mass budget:** ~8.40 kg nominal (7.06 low / 10.50 high). Printed shell 4.61 kg
  (measured) + foam 0.89 kg (all 6 wedge modules, mandated full-fill) + everything-else 2.91 kg
  (estimated — battery, solar panel/mount, stem, pod, mooring hardware still `[A]` on
  [SCO-70](https://linear.app/scout1/issue/SCO-70)).
- **Buoyancy:** max buoyant force 391 N; net reserve buoyancy ~309 N (≈31.5 kgf) at nominal.
- **Freeboard:** nominal draft **2.69 in (68 mm)**, **7.31 in freeboard** to the wedge top.
  **The buoy is substantially over-floated** — only ~9% of the 18-in float section is wetted,
  ~4.75:1 flotation margin. Bringing the waterline to mid-wedge would need +14 kg. Design
  levers: less foam, fewer/smaller wedges, or ~5 kg of low chassis ballast (also helps CG for
  [SCO-80](https://linear.app/scout1/issue/SCO-80)).
- **Failure-mode freeboard:** flooded chassis → draft ~3.3 in (still ~6.7 in freeboard); one
  wedge lost → draft barely moves but introduces a static list.
- **FEA design loads computed** (Fusion Static Stress, load table + directions in
  [Force Budget](../../engineering/buoy-structural/force-budget.md#fea-load-application--fusion-static-stress-setup)):
  LC2 vertical uplift **+322 N**, LC3 current ~14 N, LC4 wave ~185 N, LC5 aligned wave+current
  **~440 N**, wind ~50 N (acting high), LC6 resultant **586 N @ 57° from vertical**, LC7 +70 N·m
  overturning, LC8 hydrostatic **50.3 kPa** (5 m water-equivalent test spec), LC9 snap **~810 N**.
- **Proposed environmental design set** (survival): d 2 m, H 1.2 m, T 6 s, U_c 0.8 m/s,
  U_wind 22 m/s (sub-hurricane; buoy recovered ahead of a forecast hurricane). `Re` = 3.5e5,
  `KC` = 18 → C_D 1.2 (current) / 1.5, C_M 1.8 (wave). **Not signed off** — this is
  [SCO-73](https://linear.app/scout1/issue/SCO-73)'s core deliverable.
- **Flagged, not resolved:** linear (Airy) wave theory is outside its comfortable range at this
  wave (Ursell ≈ 98) — a Stokes-2nd / stream-function recheck is a final-report item.
- Prior 300 N side-load FEA (min SF 25.4) is ~1.5× under-scale vs LC5/LC6 → implied re-run
  SF ~16, still consistent with "over-engineered for the cost target."
- **Mooring attachment: through-bolted 316 pad-eye chosen** ([SCO-69](https://linear.app/scout1/issue/SCO-69),
  panel Action A1) — trade study across six options against the FEA loads; the clamped-cable
  idea was assessed and rejected (chafe at printed hole edges, wire-rope bend fatigue, hidden
  swaged termination). Cross-pin clevis retained as the fallback. Part/sizing still open.
- **FEA LC2 run** ([`mechanical/test/fea-mooring-lc2-vertical-uplift-2026-08-29.md`](../../../mechanical/test/fea-mooring-lc2-vertical-uplift-2026-08-29.md)) —
  322 N vertical uplift on the mooring attachment, custom PETG profile (E 2240, yield 35, UTS
  45 MPa; density still 1.06 g/cm³ from the old ABS profile — flagged), McMaster 3076T33
  tie-down ring stand-in. **Min SF 7.53, 0.012 mm displacement — comfortable pass.** LC3–LC9
  pending upload (top priority); LC9 snap (~810 N) is the governing case. Tracker:
  [`fea-mooring-load-cases.md`](../../../mechanical/test/fea-mooring-load-cases.md).
- **FEA LC3–LC9 + service run** (John Ryan, Fusion) — **the buoy structure passes every case**
  (LC3–LC5, service, LC8 hydrostatic: min SF 10–1450). LC6/LC9 show min SF 1.5–1.7 but John
  examined the reports and confirmed those are contact-singularity artifacts at the `3076T33`
  stand-in ring's interface, not the buoy PETG. **Buoy structure validated for now.** The final
  316 pad-eye + LC7's moment get a dedicated re-run before deployment (panel Action A1).
  Results: [`fea-mooring-load-cases.md`](../../../mechanical/test/fea-mooring-load-cases.md).
- **Turbidity sensor housing — face-seal remodel** (John Ryan) — body↔cap joint reworked to a
  static face seal: AS568-137 O-ring in a continuous face groove, mating PETG faces designed to
  fully touch (hard stop) so squeeze % is set by geometry not torque; bolt flanges reinforced
  so flange bowing between the 3 bolts doesn't drop the compression % between them. New STEP
  files supersede the prior `-current` body/cap. Custom PETG Fusion profile built for the
  structural work. See [`sensor-housing/README.md`](../../../mechanical/cad/sensor-housing/README.md#face-seal-remodel--2026-08-29).

## Still blocking

1. Complete deployed mass — battery, solar, stem, pod, mooring hardware
   ([SCO-70](https://linear.app/scout1/issue/SCO-70)) — Tier III of the mass budget
2. Environmental design set sign-off ([SCO-73](https://linear.app/scout1/issue/SCO-73))
3. Mooring scope `S` + line unit weight `w_m` for LC1 the catenary baseline
   ([SCO-69](https://linear.app/scout1/issue/SCO-69))
4. Housing dimensions ([SCO-49](https://linear.app/scout1/issue/SCO-49)),
   LiFePO₄ charging path ([SCO-10](https://linear.app/scout1/issue/SCO-10)),
   hydrophone part number ([SCO-8](https://linear.app/scout1/issue/SCO-8)) — unchanged

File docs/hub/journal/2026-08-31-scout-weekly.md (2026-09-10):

# State Snapshot — 2026-08-31 (SCOUT Weekly)

> **Summary** — Dated snapshot of where S.C.O.U.T. stood on this day. Snapshots are append-only
> history; the always-current view is [`status.md`](../status.md).
>
> Part of the [Knowledge Hub](../README.md).

---

**Phase:** 0 — Kickoff

## Where the project stands

Two of the three tracks reported themselves essentially finished for this stage of the project,
and the third was absent.

**Mechanical is done in the sense that mattered for this meeting.** John Ryan ran a full-panel
FEA covering every critical force scenario the team could construct — anchor strike, whale
impact, low-probability twist cases — and the headline result is that the **metal shackle fails
before the buoy does**. The structure is significantly overbuilt. He also rebuilt the turbidity
pod housing from scratch to industrial marine standards after the earlier leak: standardized to
O-ring sizes with a proper static face seal, engraved with the team's initials, "SCOUT",
"Electronics Housing", and the rated depth.

**Software is complete for Phase 1 and parts-limited.** Analytics and pipeline work is tested
against dummy data; firmware drivers and the real LoRa receiver are written and waiting on
hardware. Only two items on David's plate are not hardware-blocked: measurement units
([SCO-13](https://linear.app/scout1/issue/SCO-13)) and the chat assistant rename
([SCO-65](https://linear.app/scout1/issue/SCO-65)).

**Electrical is the critical path, and Isabella was not on the call.** Her open hardware
decisions — charging path, hydrophone part, base-station architecture — plus the component list
and dimensions ([SCO-70](https://linear.app/scout1/issue/SCO-70)) now gate seven blocked
mechanical issues, the Tier III mass on [SCO-74](https://linear.app/scout1/issue/SCO-74), the
parts order, and potentially the chassis print. The team's response was structural: skip the
2026-09-07 meeting and reconvene 2026-09-14, creating a deliberate two-week window for those
decisions to land and parts to arrive and be bench-tested.

Target on the table: **hardware assembled and buoy ready by October.**

## Changed today

- **Mechanical**: full-panel FEA complete; shackle identified as the weakest link. Turbidity pod
  housing remodelled around standard O-ring sizes with a static face seal
  ([SCO-91](https://linear.app/scout1/issue/SCO-91), moved to `In Progress` and given an
  assignee and project — it had neither).
- **Closed**: [SCO-69](https://linear.app/scout1/issue/SCO-69) mooring/sensor-string attachment
  point.
- **Reopened**: [SCO-74](https://linear.app/scout1/issue/SCO-74) moved back from `In Review` to
  `In Progress` and marked blocked by [SCO-70](https://linear.app/scout1/issue/SCO-70) — the
  mass budget, buoyancy numbers and freeboard model are done, but Tier III mass needs the
  electronics.
- **Five issues created**: corrosion strategy
  ([SCO-92](https://linear.app/scout1/issue/SCO-92)), Labor Day chassis print
  ([SCO-93](https://linear.app/scout1/issue/SCO-93)), pause-print threaded inserts
  ([SCO-94](https://linear.app/scout1/issue/SCO-94)), patent strategy
  ([SCO-95](https://linear.app/scout1/issue/SCO-95)), shore-to-site distance measurement
  ([SCO-96](https://linear.app/scout1/issue/SCO-96)).
- **Decisions recorded**: patent the system as a whole; defense applications declined; paid
  public API + fleet dashboard as the commercial direction; all-stainless hardware with poured
  bolt-head plugs for salt exclusion; meeting cadence moved to 2026-09-14.

## Open at end of day

- **The biofouling decision may be reversed and nobody ratified it.**
  [SCO-15](https://linear.app/scout1/issue/SCO-15) is closed with the Sea Hawk Smart Solution
  coating chosen, and `status.md` says so; the meeting ruled out anti-barnacle paint as
  reef-hostile and favoured natural growth. The coating is on the purchase list, so this needs
  settling rather than sitting. Flagged on the issue, in
  [`decision-log.md`](../decision-log.md) pending decisions, and in
  [`open-questions.md`](../research/open-questions.md) — `status.md` deliberately left alone
  until a human decides which way it goes.
- **Phase 0's end date was never actually decided.** Asked directly, John Ryan said the
  extension to 2026-09-20 was unintentional. [PR #116](https://github.com/David-Chousal/S.C.O.U.T./pull/116)
  mirrors it into the docs; resetting Linear to Sep 4 is equally defensible. Sep 20 overlaps
  Phase 1, which starts Sep 7.
- **The printed-O-ring vs [SCO-55](https://linear.app/scout1/issue/SCO-55) question has now been
  flagged in three consecutive meetings** without getting its own conversation. The housing
  remodel around off-the-shelf O-ring sizes arguably settles it in practice, but nobody said so.
- Sharp-impact and projectile cases were not modelled in the FEA panel
  ([SCO-71](https://linear.app/scout1/issue/SCO-71)).

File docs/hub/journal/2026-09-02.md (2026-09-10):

# State Snapshot — 2026-09-02

> **Summary** — Dated snapshot of where S.C.O.U.T. stood on this day. Snapshots are append-only
> history; the always-current view is [`status.md`](../status.md).
>
> Part of the [Knowledge Hub](../README.md).

---

**Phase:** 0 — Kickoff (2026-08-14 – 2026-09-04)

## Where the project stands

John Ryan carried the sensor pod's static face-seal approach across to the **electronics
housing**, producing a new clamp + lid pair and printing it. The design change closes the
2026-08-21 design panel review's lid-seal finding; the print itself did not pass — slight O-ring
tolerance trouble, reprint pending. Nothing in the water yet on either housing.

## Changed today

- **Electronics housing sealing joint reworked into a static face seal**
  ([SCO-68](https://linear.app/scout1/issue/SCO-68)). Three changes together:
  - **Fasteners moved outside the O-ring boundary** — 6 bolts on a **Ø104.14 mm bolt circle**,
    ~6.2 mm radially outboard of the groove OD (Ø91.69 mm). No fastener pierces the sealed
    region. This is the direct fix for the panel review's *"fasteners currently sit inside the
    O-ring boundary, turning every one into a potential leak path."*
  - **Groove dimensioned to a standard AS568-043 ring** — ID Ø86.87 / OD Ø91.69 mm,
    **2.413 mm wide × 1.372 mm deep** → **22.9 % squeeze, 75 % gland fill**, both inside
    standard static-face-seal practice.
  - **Reinforced, fully-contacting seal faces** — the lands bottom out land-to-land at full
    assembly, so squeeze comes from geometry rather than bolt torque, and the flange resists
    bolt-to-bolt bowing that would otherwise relieve compression between fasteners.
- **Two new CAD files:** `electronics-housing-clamp-v2-body.step` (Ø114.3 mm OD × 118.11 mm,
  Ø101.6 mm bottom spigot, Ø78.74 mm top bore, the groove and the 6-bolt pattern) and
  `electronics-housing-clamp-v2-lid.step` (Ø114.3 × 6.35 mm, engraved identifying marking).
- **Printed, needs a reprint.** Slight O-ring tolerance issues on the first print. The offending
  dimension is not yet recorded.
- **Sensor pod sealed cap re-cut** — the pilot spigot went from **Ø31.75 → Ø31.496 mm**
  (0.010" off the diameter), now line-to-line with the body bore. Committed as
  `sensor-housing-sealed-cap-v2.step`. The pod **body** re-export is geometrically identical to
  what was already committed, so no new body file.

## Baseline declared, loose ends filed

Later the same day John Ryan declared the clamp **the current electronics housing**, settling the
"two incompatible concepts in one folder" problem below: the end-cap-into-cylinder parts
(`electronics-housing-body.step`, `-endcap-no-port.step`, `-top-fitting.step`) become iteration
history. The superseded body does not mate to the clamp, so reconciling it stays an open
acceptance criterion on [SCO-68](https://linear.app/scout1/issue/SCO-68).

Everything else still unanswered was filed rather than left in prose:

| Issue | What it holds |
|---|---|
| [SCO-105](https://linear.app/scout1/issue/SCO-105) | Reprint the clamp; record which O-ring tolerance actually failed |
| [SCO-106](https://linear.app/scout1/issue/SCO-106) | Verify the AS568-043 free ID against the Ø86.87 mm groove ID; choose the elastomer; same check for AS568-137 |
| [SCO-107](https://linear.app/scout1/issue/SCO-107) | Cut the lid's bolt clearance holes; record the engraved marking's wording |
| [SCO-108](https://linear.app/scout1/issue/SCO-108) | Submersion re-test the face-seal joint on both housings, with real rings |
| [SCO-109](https://linear.app/scout1/issue/SCO-109) | Confirm the sensor pod sealed-cap spigot change was deliberate |

[SCO-68](https://linear.app/scout1/issue/SCO-68) moved to **In Progress**.

## Found by inspection, not reported

Three things came out of reading the STEP files rather than from John's account. All are
flagged in the CAD READMEs, none are resolved:

- **The lid has no clearance holes** for the clamp's 6-bolt pattern as exported.
- **Two incompatible sealing concepts now sit in the same folder** — this clamp and the older
  end-cap-slides-into-cylinder arrangement that `electronics-housing-body.step` is dimensioned
  for. Which one is baseline is undeclared.
- **The sealed-cap spigot change was not narrated** — whether it responds to a pod fit problem
  or is incidental is unconfirmed.

## Open questions raised

- **What does the lid's engraved marking actually say?** The STEP stores it as glyph geometry,
  not text, so the wording is not recoverable from the file — it needs recording from John so a
  future print is reproducible from the repo alone.
- **Does the AS568-043 free ID fit the Ø86.87 mm groove ID?** The squeeze and fill checks pass
  on cross-section; the diameter fit has not been checked against a supplier table.
- **Which O-ring tolerance failed on the print?** Capture it on the reprint so the groove
  numbers can be corrected rather than re-guessed.

## Still open from before

Unchanged: environmental design set sign-off ([SCO-73](https://linear.app/scout1/issue/SCO-73)),
mooring pad-eye sizing ([SCO-69](https://linear.app/scout1/issue/SCO-69)), housing internal
dimensions ([SCO-49](https://linear.app/scout1/issue/SCO-49)), print material
([SCO-64](https://linear.app/scout1/issue/SCO-64)), and a **submersion re-test of the new
sealing joint** on both the clamp and the remodelled sensor pod.

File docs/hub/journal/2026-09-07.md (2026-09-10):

# State Snapshot — 2026-09-07

> **Summary** — Dated snapshot of where S.C.O.U.T. stood on this day. Snapshots are append-only
> history; the always-current view is [`status.md`](../status.md).
>
> Part of the [Knowledge Hub](../README.md).

---

**Phase:** 0 — Kickoff (2026-08-14 – 2026-09-20)

## Where the project stands

John Ryan iterated the flotation wedge to a **thin-wall v5** — 5.5-in height
([SCO-110](https://linear.app/scout1/issue/SCO-110)), outer curved wall 0.095 in, radial side
walls 0.063 in — chasing print mass and material cost. The thin open walls flexed during
printing and broke first-layer bed adhesion; the fix was an **internal bracing web with
lightening cutouts**. A closed-form structural check was run against the wedge-relevant load
cases. Nothing else moved.

## Changed today

- **Flotation wedge v5 (thin walls + DFM bracing web)** — full narrative in
  [`design-notes.md`](../design-notes.md) and
  [`mechanical/cad/floatation/README.md`](../../../mechanical/cad/floatation/README.md#thin-wall--dfm-bracing-web-iteration-v5--2026-09-07).
  - Walls thinned over several slicing passes to **outer 0.095 in / sides 0.063 in**, both now
    fully-dense perimeter shells (no infill core) — a change from v4's "3–4 walls + 15 %
    gyroid."
  - **Internal bracing web** added to connect the previously-open walls. **DFM fix and
    structural fix in one change** — it stops the print-bed flex *and* halves every wall
    panel's free span *and* adds a third shear web to the wedge-to-chassis load path.
- **Wall-thickness structural check** —
  [`mechanical/test/wedge-wall-thickness-structural-check-2026-09-07.md`](../../../mechanical/test/wedge-wall-thickness-structural-check-2026-09-07.md).
  Closed-form hand calcs against LC3–LC5 (wave/current), LC8 (50.3 kPa hydrostatic), plus
  foam-fill expansion and print/handling flex.
  - **Outer wall 0.095 in — accepted as the floor.** SF 7.3 on yield under LC8; buckling
    suppressed foam-backed. Do not thin further.
  - **Side walls 0.063 in — accepted.** John pointed out each radial side wall is paired
    face-to-face with the neighbouring wedge, then confirmed the assembly: the six wedges are
    **exactly 60°** (faces tile in contact), the **radial seams are epoxied**, and **foam is
    poured after the wedges are bolted into the ring**. That makes them an epoxied closed
    monocoque ring — no through-thickness service pressure on a side wall, a bonded 3.2 mm
    composite seam (compression-ring path + stiff stringer), foam-fill pressure reacted by the
    bonded neighbour. The 0.080 in alternative from the first draft is moot.
  - **Internal bracing web is mandatory**, not optional.
- **Decision logged** ([`decision-log.md`](../decision-log.md)) and canonical values updated
  ([`facts.md`](../facts.md), [`print-settings.md`](../../engineering/buoy-structural/print-settings.md)).

## The consequence that matters

**The failure philosophy shifts: the epoxied 6-wedge ring is the primary structure; the foam
is required backing.** At the v4 0.250-in wall the single printed shell was self-supporting and
the foam was a bonus (cracked-wedge-keeps-buoyancy). At 0.095 in a *single bare panel* is
marginal on external-pressure buckling — but the confirmed assembly is an **epoxied closed
monocoque ring**, a much stiffer structure against uniform pressure (needs an assembly-level
buckling FEA to quantify). Practical effects:

- Foam must be in **before any submersion or pressure test** — conservatively, until the
  ring-buckling FEA is run.
- Foam is genuinely load-bearing against **local/asymmetric loads** (wave slam on one face,
  impact, one flooded neighbour) regardless of that FEA — it's a distributed elastic foundation
  on every panel.
- Foam fill + shell adhesion becomes a **structural sign-off item**, not just a process step.
- A *cracked but foam-filled* wedge still keeps its buoyancy (unchanged — closed-cell foam
  doesn't flood).

## Still open / next

- **Export the v5 STEP + dimensioned PDF**, rotate `mechanical/cad/floatation/current/`, and
  confirm the **~0.69-in inner bolt flange** survived (bolt loads must not land on the thin
  walls). Check the first six-wedge dry-fit seats on the chassis without forcing (6 × exactly
  60° has no designed clearance) — John.
- **Assembly-level ring-buckling FEA** of the epoxied 6-wedge ring — add to
  [SCO-71](https://linear.app/scout1/issue/SCO-71) / [SCO-73](https://linear.app/scout1/issue/SCO-73)
  scope; it's what would let the foam-before-submersion rule relax.
- **Mass / buoyancy / freeboard recompute** with real re-sliced weights —
  [SCO-110](https://linear.app/scout1/issue/SCO-110) acceptance criteria.
- **Impact / boat-strike check at the v5 wall spec** — [SCO-71](https://linear.app/scout1/issue/SCO-71);
  the thinner wall is materially more impact-sensitive and the 2026-08-17 FEA (6.35 mm wall,
  SF 25.4) does not transfer.
- **Environmental design set sign-off** — [SCO-73](https://linear.app/scout1/issue/SCO-73);
  loads used in the check are proposed, not signed off (headroom is large).

## Unchanged from before

Environmental design set sign-off ([SCO-73](https://linear.app/scout1/issue/SCO-73)), mooring
pad-eye sizing ([SCO-69](https://linear.app/scout1/issue/SCO-69)), housing internal dimensions
([SCO-49](https://linear.app/scout1/issue/SCO-49)), print material
([SCO-64](https://linear.app/scout1/issue/SCO-64)), the electronics-housing clamp reprint
([SCO-105](https://linear.app/scout1/issue/SCO-105)) and its submersion re-test
([SCO-108](https://linear.app/scout1/issue/SCO-108)).

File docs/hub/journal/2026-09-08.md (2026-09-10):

# State Snapshot — 2026-09-08

> **Summary** — Dated snapshot of where S.C.O.U.T. stood on this day. Snapshots are append-only
> history; the always-current view is [`status.md`](../status.md).
>
> Part of the [Knowledge Hub](../README.md).

---

**Phase:** 0 — Kickoff (2026-08-14 – 2026-09-20)

## Where the project stands

Session decision sweep — John closed out a batch of GENG calls that were sitting as
"Needs Decision" or as flagged contradictions, none of which needed new analysis:

- **Biofouling: the antifouling coating stands.** The 2026-08-31 meeting had leaned toward
  abandoning a coating and letting natural growth occur; John ruled to keep an antifouling
  coating (Sea Hawk Smart Solution, copper-free — product choice unchanged). Resolves the
  [meeting-notes 2026-08-31 §Flagged](../../planning/meeting-notes.md) contradiction and
  [SCO-15](https://linear.app/scout1/issue/SCO-15).
- **Environmental design set for the structural FEA signed off** — `d` 2.0 m, `H` 1.2 m,
  `T_w` 6 s, `U_c` 0.8 m/s, `U_wind` 22 m/s (survival). The proposed set accepted verbatim, so
  LC3–LC9 as already computed and FEA-run stand with no re-run.
  [SCO-73](https://linear.app/scout1/issue/SCO-73) now covers only the final Cd/Cm/Ca
  DNV-RP-C205 table pull and the Ursell-number wave-theory recheck.
- **Structural print material: PETG for the build**, ASA documented as the viable scale-up
  material; the ABS / SLA / nylon comparison is dropped ([SCO-64](https://linear.app/scout1/issue/SCO-64)).
- **Housing seal elastomer: silicone**, electronics housing and sensor pod, for seawater + UV
  service and low compression set ([SCO-106](https://linear.app/scout1/issue/SCO-106) — ring
  free-diameter fit still to verify).
- **Mooring/tether line: 3-strand twisted nylon, 3/8 in** — twisted so a crossing propeller
  fouls rather than cuts, nylon for catenary shock compliance. Closes the ADR-0004 loose end
  and [SCO-72](https://linear.app/scout1/issue/SCO-72); pins the line unit weight `w_m` for the
  LC1 catenary case (scope `S` still on [SCO-17](https://linear.app/scout1/issue/SCO-17)).
- **Electronics-housing lid engraving** wording set (four lines): `S.C.O.U.T.` /
  `SCU Senior Design 2026–2027` / `+1 808-745-0769` / `IR · JRM · DCC`. Recorded in
  [`electronics-housing/README.md`](../../../mechanical/cad/electronics-housing/README.md) so a
  reprint is reproducible from the repo; bolt-clearance holes still uncut
  ([SCO-107](https://linear.app/scout1/issue/SCO-107)).
- **Flotation-wedge fill foam: US Composites #0204 2 lb/ft³ closed-cell rigid PU pour foam.**
  Cost-effective standard; ~2 ft³ per 4 lb kit covers the ~1 ft³ six-wedge fill, ~2 kits for
  overpack. ~30–40 psi compressive exceeds the generic value the 2026-09-07 wall check assumed,
  so that result stays conservative. Ordered from a composites supplier — Home Depot has no
  suitable structural pour foam ([SCO-76](https://linear.app/scout1/issue/SCO-76)).

## CAD brought into the repo (later the same day)

- **v5 wedge STEP** — [`chassis-floatation-bolted-v5-wedge.step`](../../../mechanical/cad/floatation/chassis-floatation-bolted-v5-wedge.step)
  committed (top level, not `current/` yet). STEP confirms the SCO-110 resize: height
  203.2 → 139.7 mm (8.00 → 5.50 in), outer radius unchanged. John added a functional twist to
  the internal web — it's now a **perforated compliant panel between the bolt flanges** that
  flexes to seat around the chassis and gives service access. v5 chassis + caps + a dimensioned
  PDF still pending before `current/` rotates.
- **Turbidity sensor housing** — John re-sent the sealed cap + no-port body; both are
  **byte-identical geometry** to the committed `-v2` cap and face-seal body, so no new files.
  Confirms those as his current parts (and confirms the Ø31.496 mm cap spigot that had been
  flagged "not narrated"). **Flood chamber deliberately not included — being re-specced.**
- **New task (needs a Linear issue):** John to examine Isabella's actual Rev A turbidity sensor
  and adapt the flood chamber + body around it, rather than the generic SEN0189 the pod was
  first drawn to. Feeds the flood-chamber re-spec ([SCO-91](https://linear.app/scout1/issue/SCO-91)).

## Still open / next

- **Assembly-level ring-buckling FEA** of the epoxied 6-wedge ring, now using the chosen foam's
  real datasheet values — it's what would let the foam-before-submersion rule relax. Tied to
  [SCO-71](https://linear.app/scout1/issue/SCO-71) / [SCO-73](https://linear.app/scout1/issue/SCO-73).
- v5 chassis + cap re-exports and a dimensioned wedge PDF (then rotate `current/`),
  mass/freeboard recompute ([SCO-110](https://linear.app/scout1/issue/SCO-110)),
  impact check at the v5 wall spec ([SCO-71](https://linear.app/scout1/issue/SCO-71)).
- Electronics-housing clamp reprint ([SCO-105](https://linear.app/scout1/issue/SCO-105)) and
  submersion re-test of the new sealing joint ([SCO-108](https://linear.app/scout1/issue/SCO-108)).
- Electronics component list + dimensions from Isabella by 2026-09-14
  ([SCO-70](https://linear.app/scout1/issue/SCO-70)) — still the largest single blocker on the
  mechanical side.

## Unchanged from before

Firmware and shore station in progress behind Rev A hardware bring-up
([SCO-88](https://linear.app/scout1/issue/SCO-88)); electrical design in pre-hardware
verification pending parts; LiFePO₄ charging path still open
([ADR-0002](../../decisions/0002-lifepo4-charging-path.md), [SCO-10](https://linear.app/scout1/issue/SCO-10));
hydrophone part number unresolved ([SCO-8](https://linear.app/scout1/issue/SCO-8)).

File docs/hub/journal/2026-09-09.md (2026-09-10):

# State Snapshot — 2026-09-09

> **Summary** — Dated snapshot of where S.C.O.U.T. stood on this day. Snapshots are append-only
> history; the always-current view is [`status.md`](../status.md).
>
> Part of the [Knowledge Hub](../README.md).

---

**Phase:** 0 — Kickoff (2026-08-14 – 2026-09-20)

## Where the project stands

Session: a Linear housekeeping sweep followed by the v5 buoyancy/freeboard rebuild.

### Linear sweep (GENG)

- **[SCO-48](https://linear.app/scout1/issue/SCO-48) closed** — the floatation-iteration choice
  (bolted-wedge family → v5 at the SCO-110 dimensions) is made and documented across the hub
  decision-log and design-notes. The one remaining acceptance criterion — buoyancy vs. loaded
  electronics weight — depends on [SCO-70](https://linear.app/scout1/issue/SCO-70) and was moved
  to [SCO-74](https://linear.app/scout1/issue/SCO-74). The SCO-70 / SCO-49 blocking relations
  were removed from SCO-48 (the design decision was not waiting on them).
- **[SCO-70](https://linear.app/scout1/issue/SCO-70) escalated to Urgent** — it is now the
  single gate on the mechanical side: SCO-49, SCO-53, SCO-73, SCO-75, SCO-81 (and partly SCO-68)
  are all `blockedBy` it and have been stalled 2–3 weeks. Comment left asking Isabella for at
  minimum a rough bounding-box envelope of the electronics stack + battery + connectors.
- **[SCO-93](https://linear.app/scout1/issue/SCO-93) reworded** — dropped "over Labor Day" (the
  window passed); added a precondition note that the v5 chassis STEP has not been re-exported,
  so the geometry is not frozen for a 35-hour print.
- **[SCO-74](https://linear.app/scout1/issue/SCO-74) rescoped** to the v5 dimension rebuild
  (see below) and kept In Progress.

The genuinely-stale GENG issues (SCO-49, SCO-53, SCO-75, SCO-81) are all correctly parked
`Blocked` behind SCO-70 — the stale flag there means *chase the blocker*, not *close the
ticket*.

### v5 whole-buoy mass / freeboard model rebuild ([SCO-74](https://linear.app/scout1/issue/SCO-74))

Re-solved the whole-buoy mass, displacement, and freeboard model on the **v5 geometry** —
wedge shell 8.0 → 5.5 in, chassis 11.0 → 8.5 in, wedge walls 0.250 in uniform →
0.095 in outer / 0.063 in sides + web, outer radius R9.000 in unchanged. The method is
unchanged from the 2026-08-29 v4 build (same formulas, same 0.372 kg appendage credit, same
piecewise `V_disp(T)`, same tier structure) — only geometry inputs moved — so verification was
one careful pass + **one independent agent re-deriving every headline number** (agreed to
< 0.5 %), not the full multi-agent treatment used for v4.

| Quantity | v4 (2026-08-29) | **v5 (2026-09-09)** |
|---|---:|---:|
| Nominal all-up mass | 8.40 kg | **~7.59 kg** |
| Max buoyant force | 391 N | **286 N** |
| Net reserve buoyancy (nominal) | 309 N | **~212 N** |
| Reserve ratio `F_B,max / W_nom` | 4.75× | **3.84×** |
| Nominal draft | 2.69 in | **2.50 in** |
| Freeboard to wedge top | 7.31 in | **~5.0 in** (of a 5.5-in float section) |
| Float section wetted | 8.6 % | **9.1 %** |
| Foam-alone buoyancy (shell gone), ×6 | 271 N | **216 N** |

The "**substantially over-floated, waterline/CG is the real problem, not flotation**"
conclusion survives the resize — the 3.84× margin matches the "~3.9× nominal" the SCO-110
decision was sized against. The margin has eroded from "huge" to "healthy"; a further
wedge-height cut or the high-mass estimate (~3.2×) would move the phrasing toward "comfortably"
rather than "substantially" over-floated.

Recorded in:
[`buoy-mass-displacement-and-freeboard-model.md`](../../engineering/buoy-structural/buoy-mass-displacement-and-freeboard-model.md)
(v5 is now the live model; v4 preserved verbatim as §14),
[`mass-and-buoyancy-budget.md` §12](../../engineering/buoy-structural/mass-and-buoyancy-budget.md#12-v5-revision--sco-110-resize--thin-walls),
[`facts.md`](../facts.md#mechanical--deployment), [`design-notes.md`](../design-notes.md),
[`decision-log.md`](../decision-log.md), [`status.md`](../status.md).

### EDD mechanical reconciliation

The [Engineering Design Document](../../engineering/engineering-design-document.md) was bumped
**v0.2 → v0.3** and its **mechanical architecture (§4) fully reconciled** against the
2026-08-14 → 2026-09-09 detailed design work — it had not been touched substantively since v0.1
and still described a "4-inch Schedule 40 PVC" housing, a "fixed mooring", and no six-wedge
float. §4 now covers: the bolted six-wedge flotation (v5 geometry), the foam-filled epoxied
monocoque ring, the buoyancy/freeboard model, the static face-seal lid, the reef-safe mooring +
316 pad-eye load path, the LC1–LC9 structural framework + FEA results, the waterproofing
strategy, materials/manufacturing, biofouling, and a table of every open mechanical item with
its blocking issue. Mechanical touchpoints in §§1–3, 18, 19, 21, 22 updated (new Mechanical
Assumptions table, real mechanical BOM, expanded Phase 6 test plan).

**Not done:** §§5–17 and §20 (electrical, power, sensor, audio, comms, firmware, storage,
energy budget) still reflect the earlier baseline — a banner at the top of the EDD says so and
names ECE/CSEN as owners. Decisions since (FCC LoRa config, packet size, turbidity units,
ADR-0005/0006) are in the Hub but not yet folded into those sections.

### v5 structural analyses — the owed closed-form work

Worked the four analyses the freeboard model and force budget had been deferring, all on the v5
geometry, as closed-form hand calculations with the derivations shown:

1. **Stability ([SCO-80](https://linear.app/scout1/issue/SCO-80))** — full `KG`/`KB`/`BM`/`GM`
   derivation. `GM` ≈ **9.7 in (0.25 m)**, ~10× a typical adequacy target — emphatically
   self-righting. Natural **roll period ~0.6 s** (≪ the 6 s design wave → no resonance, but a
   stiff snappy response: a component-retention + hydrophone-self-noise note, not a stability
   problem). **One flotation wedge lost → ~3° static list.** Under the peak
   mooring/environmental load the LC7 overturning moment (~42 N·m at v5) **exceeds** the bare
   hydrostatic righting `W·GM` (~18 N·m), so the buoy heels into the flow under load —
   sustained current-only heel ~2°, the transient wave-driven peak and the large-angle `GZ`
   curve open, deferred to a coupled mooring analysis + the [SCO-82](https://linear.app/scout1/issue/SCO-82)
   tilt/proof-load test. New doc: [`stability-analysis.md`](../../engineering/buoy-structural/stability-analysis.md).

2. **Ring buckling** — closed-form external-pressure buckling of the thinned v5 wedge wall.
   **Bare:** `SF` ≈ 0.2–0.7 (fails). **Foam-backed:** `SF` ≈ 3–5. Quantifies and hardens
   "foam in before submersion". New doc:
   [`wedge-ring-buckling-check-2026-09-09.md`](../../../mechanical/test/wedge-ring-buckling-check-2026-09-09.md).

3. **Impact / boat strike ([SCO-71](https://linear.app/scout1/issue/SCO-71))** — energy method.
   Drift contact (≤ 1 m/s) does no damage. A **direct strike above ~1.5–2 m/s cracks the v5
   wedge shell** (equivalent static load ~1–3.5 kN). Held acceptable per the 2026-08-18
   validation-target pivot: foam → no flood/no buoyancy loss, epoxied ring → no collapse, wedges
   outside the sealed chassis and field-replaceable. Handling: set the buoy on its base, never a
   sidewall; carry 1–2 spare wedges. New doc:
   [`impact-survivability-analysis.md`](../../engineering/buoy-structural/impact-survivability-analysis.md).
   Dynamic FEA + bench drop tests still owed.

4. **v5 load reassessment** — recomputed LC1–LC9 at the v5 geometry. **Every environmental and
   mooring load is 10–30% lower than v4**; LC8 (hydrostatic, 5 m test spec) unchanged. The
   2026-08-29 FEA passed every case on v4 at the higher loads, so **the v4 runs bound v5 for
   load adequacy — no urgent full FEA re-run.** Three v5-specific checks still needed (thin-wall
   wedge stress, assembly ring-buckling, final pad-eye). Added as a section to
   [`force-budget.md`](../../engineering/buoy-structural/force-budget.md#v5-geometry-reassessment-2026-09-09).

## Still open / next

- ⚠️ **v5 shell masses are geometric estimates** (wedge ~240 g, chassis ~600 g) — no re-slice
  exists. This is [SCO-110](https://linear.app/scout1/issue/SCO-110)'s one unchecked acceptance
  box; the model is provisional on it. The v5 wedge **displacement** and **cavity** are exact
  from geometry — only the printed mass is estimated.
- **FEA re-check of the v5 geometry** — the 2026-08-29 Fusion FEA ran on v4. Buoy OD is
  unchanged and draft moved only −0.2 in, so the loads are approximately still valid, but the
  resize (and the lower solar deck) needs a re-run before deployment. Folded into
  [SCO-73](https://linear.app/scout1/issue/SCO-73) / [SCO-71](https://linear.app/scout1/issue/SCO-71).
- **[SCO-70](https://linear.app/scout1/issue/SCO-70)** — electronics list + dimensions from
  Isabella (was due 2026-09-04). Still the largest single blocker on the mechanical side; now
  Urgent.
- v5 chassis + cap STEP re-exports and a dimensioned wedge PDF, then rotate
  `mechanical/cad/floatation/current/`.

## Unchanged from before

Firmware and shore station in progress behind Rev A hardware bring-up
([SCO-88](https://linear.app/scout1/issue/SCO-88)); LiFePO₄ charging path still open
([ADR-0002](../../decisions/0002-lifepo4-charging-path.md), [SCO-10](https://linear.app/scout1/issue/SCO-10));
hydrophone part number unresolved ([SCO-8](https://linear.app/scout1/issue/SCO-8)); base-station
node architecture still `Needs Decision` ([SCO-86](https://linear.app/scout1/issue/SCO-86)).

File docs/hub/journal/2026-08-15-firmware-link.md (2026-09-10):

# State Snapshot — 2026-08-15 (firmware link reliability)

> **Summary** — Dated snapshot of where S.C.O.U.T. stood on this day. Snapshots are append-only
> history; the always-current view is [`status.md`](../status.md). Second entry for 2026-08-15;
> the first covers the telemetry drift work.
>
> Part of the [Knowledge Hub](../README.md).

---

**Phase:** 0 — Kickoff (2026-08-14 – 2026-09-04)

## Where the project stands

Phase 0's three blockers are unchanged and all remain hardware calls. Today's work continued
down the software-only CSEN track:
[SCO-21](https://linear.app/scout1/issue/SCO-21), daily-packet delivery reliability.

## Changed today

- **CR 4/8 + blind repetition implemented.** The daily packet now goes out three times in
  NORMAL (once in CONSERVE, never in CRITICAL), spaced with widening gaps so the copies do not
  share a single fade, with no acknowledgement and no retransmit. Policy lives in the new
  hardware-free `firmware/lib/scout_link` and is unit-tested off-target, including a guard that
  the repeat schedule cannot outrun the 16 s watchdog.
- **The shore station now deduplicates** on `(buoy_id, record_seq)`. This was not in the
  ticket, but blind repetition without it would have written three identical CSV rows per day
  and pushed `qc.py`'s completeness figure to 100% while real gaps went unnoticed.
- **Spreading factor deliberately left at SF7.** RadioHead's only stock CR 4/8 presets force
  SF12, whose ~2.2 s airtime for a 30-byte frame would overrun the transmit budget *and* the
  400 ms per-channel dwell limit in FCC 15.247. Whether that rule binds S.C.O.U.T. is
  [SCO-19](https://linear.app/scout1/issue/SCO-19), still open, so the SF choice was left to it.

## Raised today

- **The firmware had never compiled for its own target.** Three independent breakages had
  accumulated on `main`: a `platformio.ini` dependency ID that does not resolve, a `class Rtc`
  colliding with the SAMD21 CMSIS `Rtc` peripheral union, and `PM->RCAUSE.bit.WDT` expanding
  the CMSIS `WDT` macro. All three are fixed; the build is clean at RAM 18.8%, Flash 22.6%.
- **Root cause was a CI gap, not carelessness.** CI ran only `pio test -e native`, which
  excludes `src/` and never includes CMSIS — it structurally cannot catch a target compile
  break. `pio run -e feather_m0` is now a CI step, so this cannot recur.
- Consequence worth noting: every firmware claim made before today rested on unit tests of the
  hardware-free libraries only. Those tests were and remain valid; the target build was not
  being checked at all.

## Still blocking

Unchanged — all three are ECE/hardware decisions:

1. LiFePO₄ charging path ([SCO-10](https://linear.app/scout1/issue/SCO-10))
2. Hydrophone part number ([SCO-8](https://linear.app/scout1/issue/SCO-8))
3. Dissolved-oxygen inclusion ([SCO-11](https://linear.app/scout1/issue/SCO-11))

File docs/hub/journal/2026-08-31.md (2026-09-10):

# State Snapshot — 2026-08-31

> **Summary** — Dated snapshot of where S.C.O.U.T. stood on this day. Snapshots are append-only
> history; the always-current view is [`status.md`](../status.md).
>
> Part of the [Knowledge Hub](../README.md).

---

**Phase:** 0 — Kickoff (2026-08-14 – 2026-09-20)

## Where the project stands

Two housekeeping corrections, both surfaced while briefing a team meeting off the live Linear
board rather than off the repo.

The first is a date drift. Linear's Phase 0 project had been extended to **2026-09-20** at some
point, but four documents still carried the original **Sep 4** end date. Nobody had noticed
because the phase table is read far more often than it is edited. Linear was taken as correct
and the documents now mirror it.

The second is that [`status.md`](../status.md)'s blocker list had fallen behind the board. It
still named the dissolved-oxygen decision ([SCO-11](https://linear.app/scout1/issue/SCO-11)) as
a top-four blocker after that issue closed, and it did not name
[SCO-70](https://linear.app/scout1/issue/SCO-70) at all — despite seven mechanical issues now
sitting `Blocked` behind it. The subsystem table was current; the blocker summary above it was
not.

## Changed today

- **Phase 0 window corrected to Aug 14 – Sep 20, 2026** across `CLAUDE.md`,
  [`team-timeline.md`](../../planning/team-timeline.md),
  [`linear-backlog.md`](../linear-backlog.md), and [`status.md`](../status.md). Phase 0 is a
  five-week phase, not three.
- **`status.md` blocker list rewritten** against the current board:
  [SCO-70](https://linear.app/scout1/issue/SCO-70) (electronics component list and dimensions)
  promoted to the top blocker with its seven downstream issues named explicitly;
  [SCO-88](https://linear.app/scout1/issue/SCO-88) (Rev A parts not arrived) added, since it is
  what actually holds firmware and shore-station bring-up;
  [SCO-11](https://linear.app/scout1/issue/SCO-11) removed and recorded as closed.
- **Mechanical detail extended** past the 2026-08-29 snapshot with the LC3–LC9 and
  service-mooring FEA runs ([SCO-73](https://linear.app/scout1/issue/SCO-73)) and the turbidity
  housing face-seal remodel ([SCO-91](https://linear.app/scout1/issue/SCO-91)).

## Open at end of day

- **Phase 0 now overlaps Phase 1** (Sep 7 – Oct 16) by two weeks. The overlap is recorded, not
  resolved — whether Phase 1 shifts or the two run concurrently is a team call, and the
  timeline document still describes them as sequential.
- Five issues carry no assignee ([SCO-86](https://linear.app/scout1/issue/SCO-86) through
  [SCO-90](https://linear.app/scout1/issue/SCO-90)); [SCO-91](https://linear.app/scout1/issue/SCO-91)
  has no phase project either.
- Four Phase 0 decisions remain open with three weeks left in the phase:
  [SCO-8](https://linear.app/scout1/issue/SCO-8),
  [SCO-10](https://linear.app/scout1/issue/SCO-10),
  [SCO-13](https://linear.app/scout1/issue/SCO-13),
  [SCO-86](https://linear.app/scout1/issue/SCO-86).

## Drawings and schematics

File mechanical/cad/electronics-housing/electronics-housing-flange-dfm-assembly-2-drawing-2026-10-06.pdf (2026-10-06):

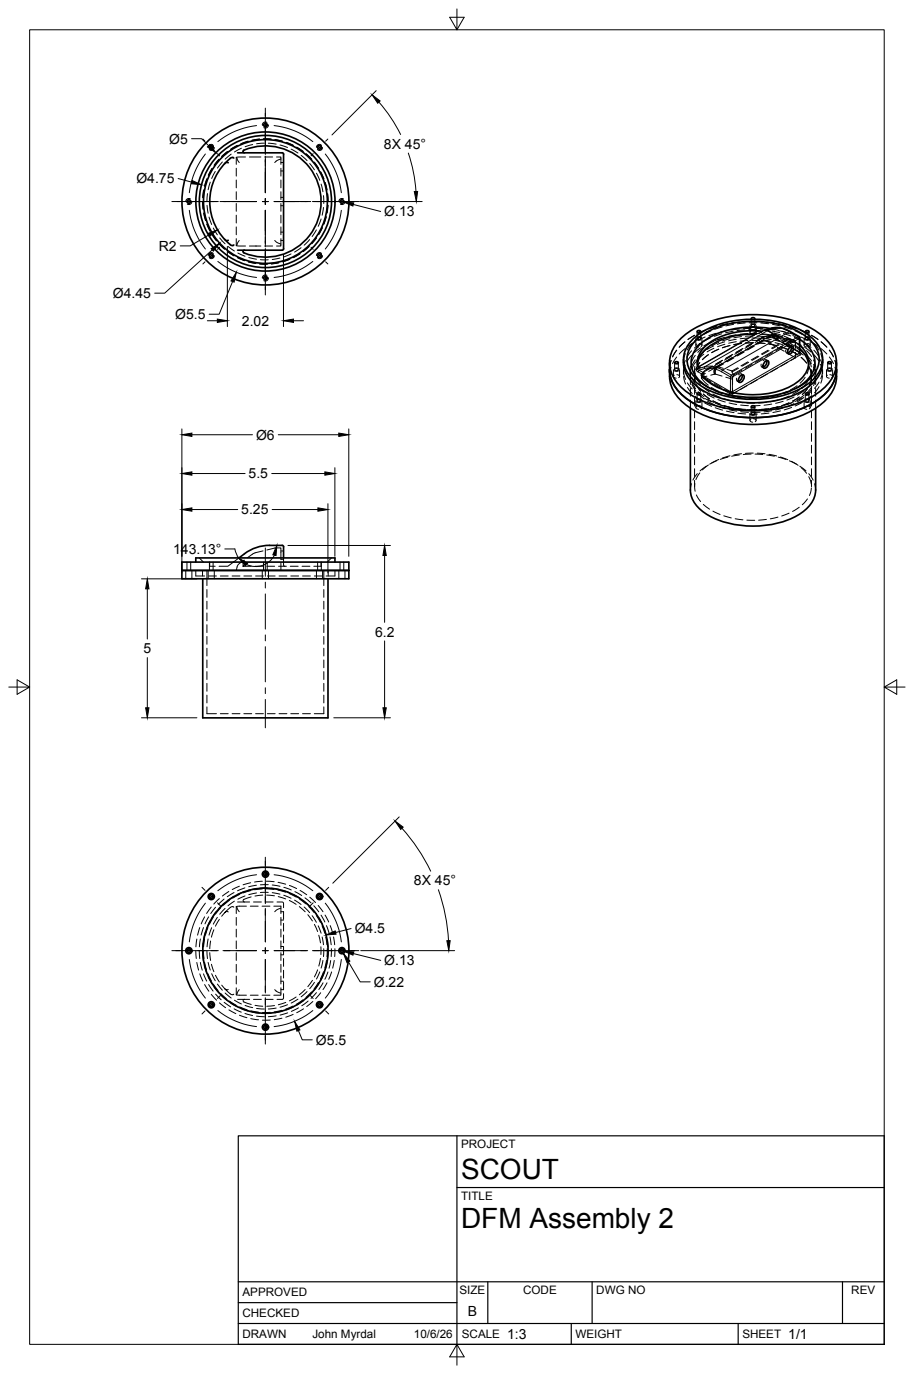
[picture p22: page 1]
SIZE; CODE; DWG NO; REV; John Myrdal; DFM Assembly 2

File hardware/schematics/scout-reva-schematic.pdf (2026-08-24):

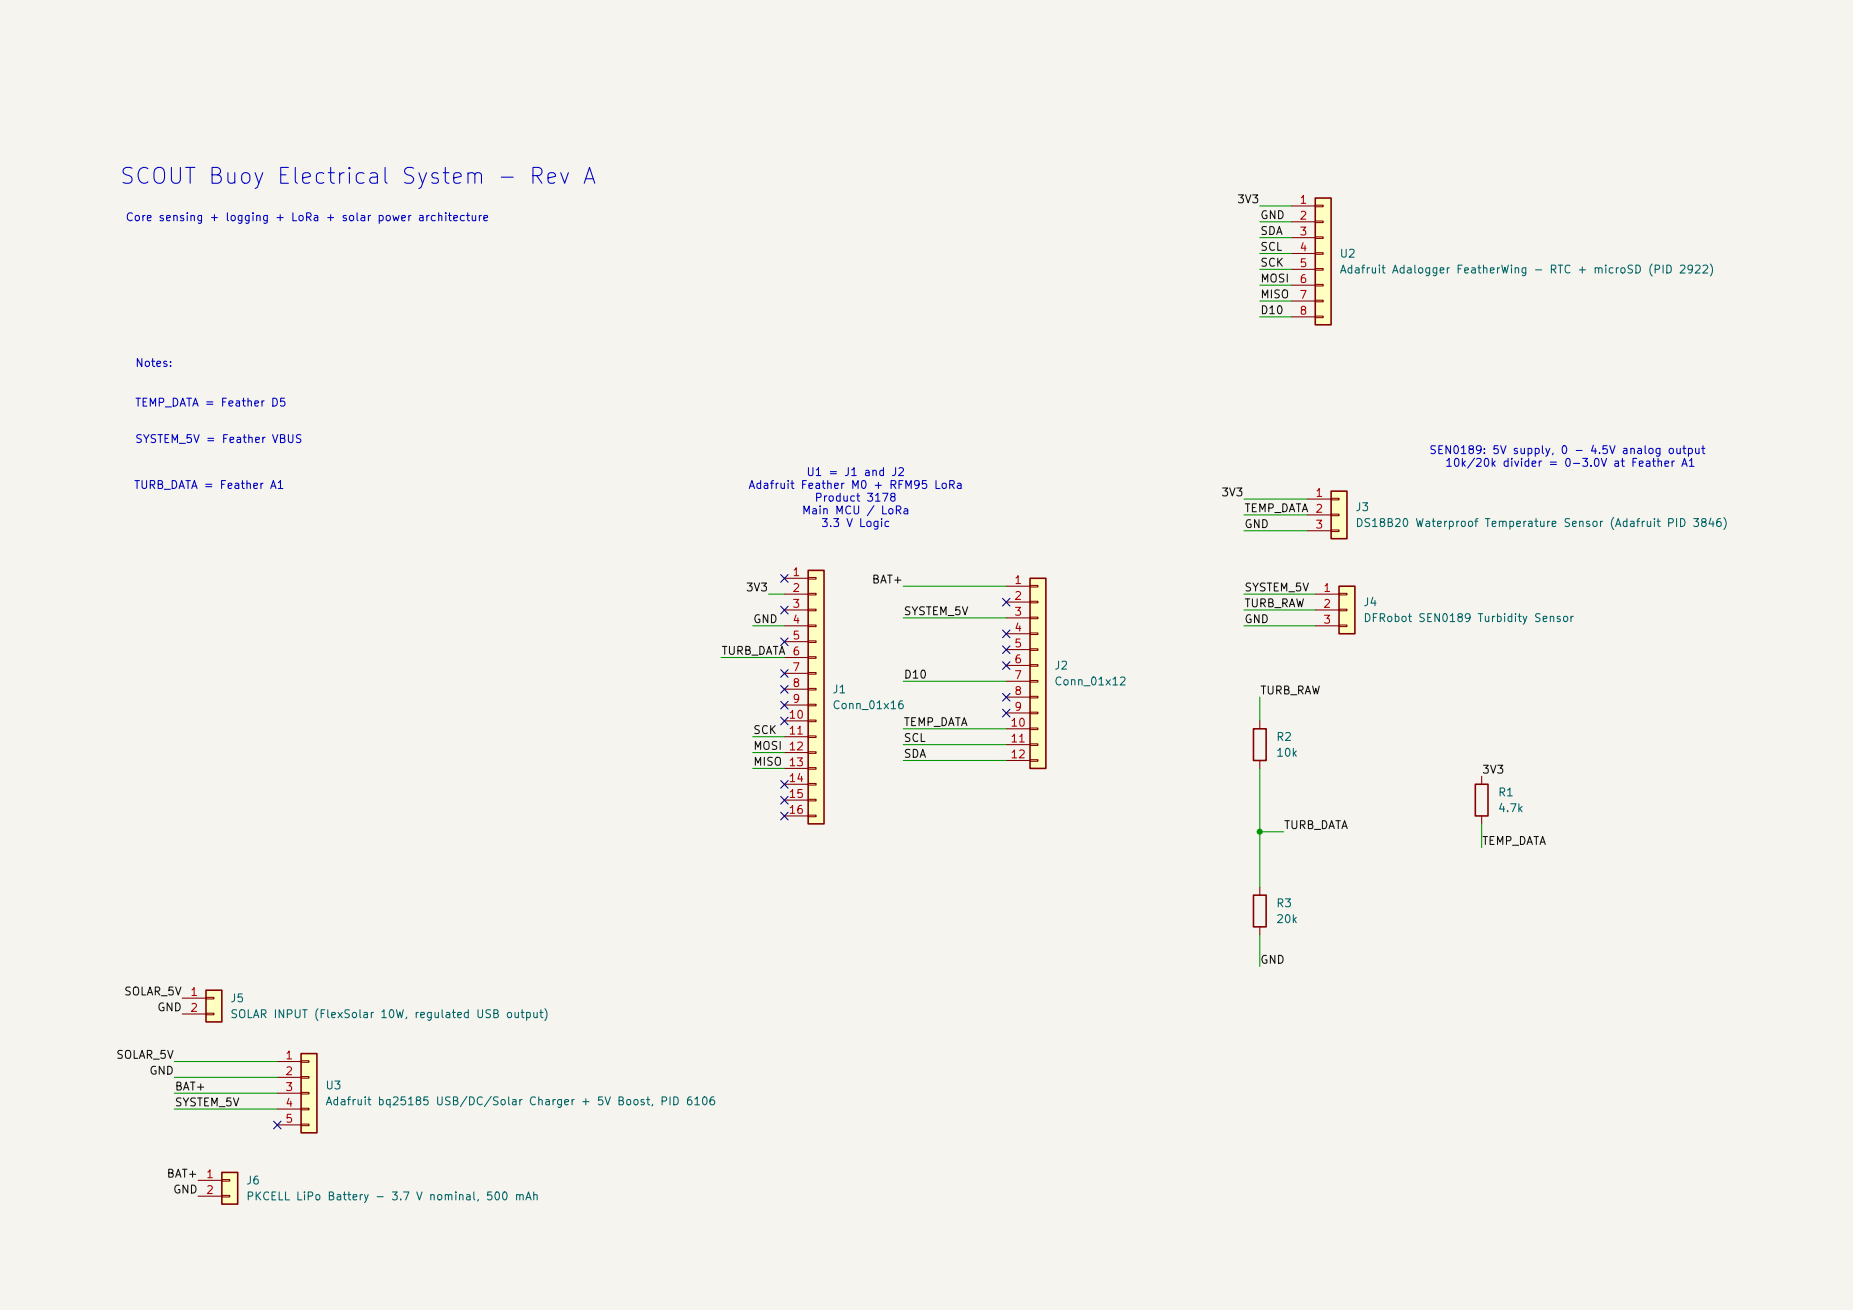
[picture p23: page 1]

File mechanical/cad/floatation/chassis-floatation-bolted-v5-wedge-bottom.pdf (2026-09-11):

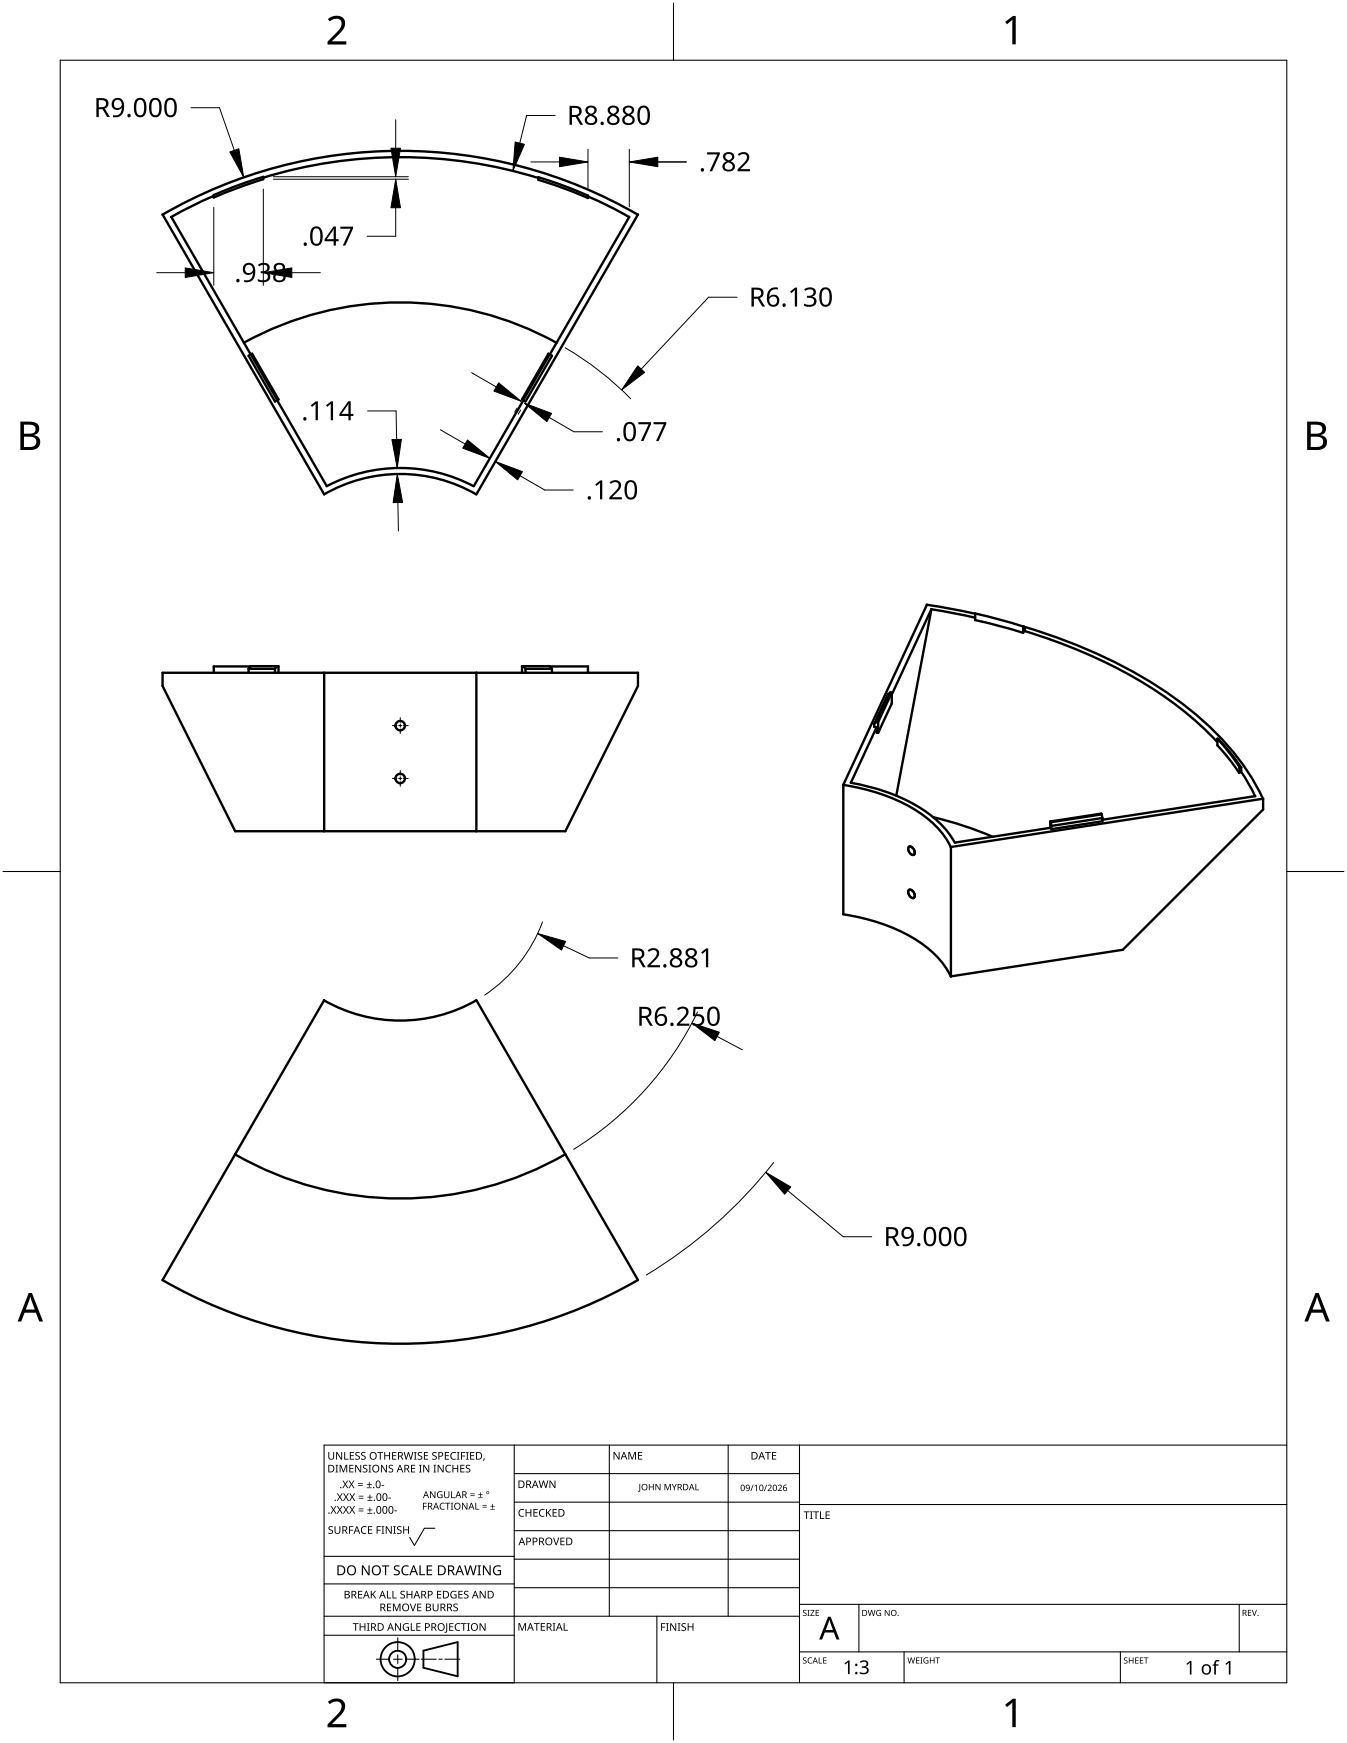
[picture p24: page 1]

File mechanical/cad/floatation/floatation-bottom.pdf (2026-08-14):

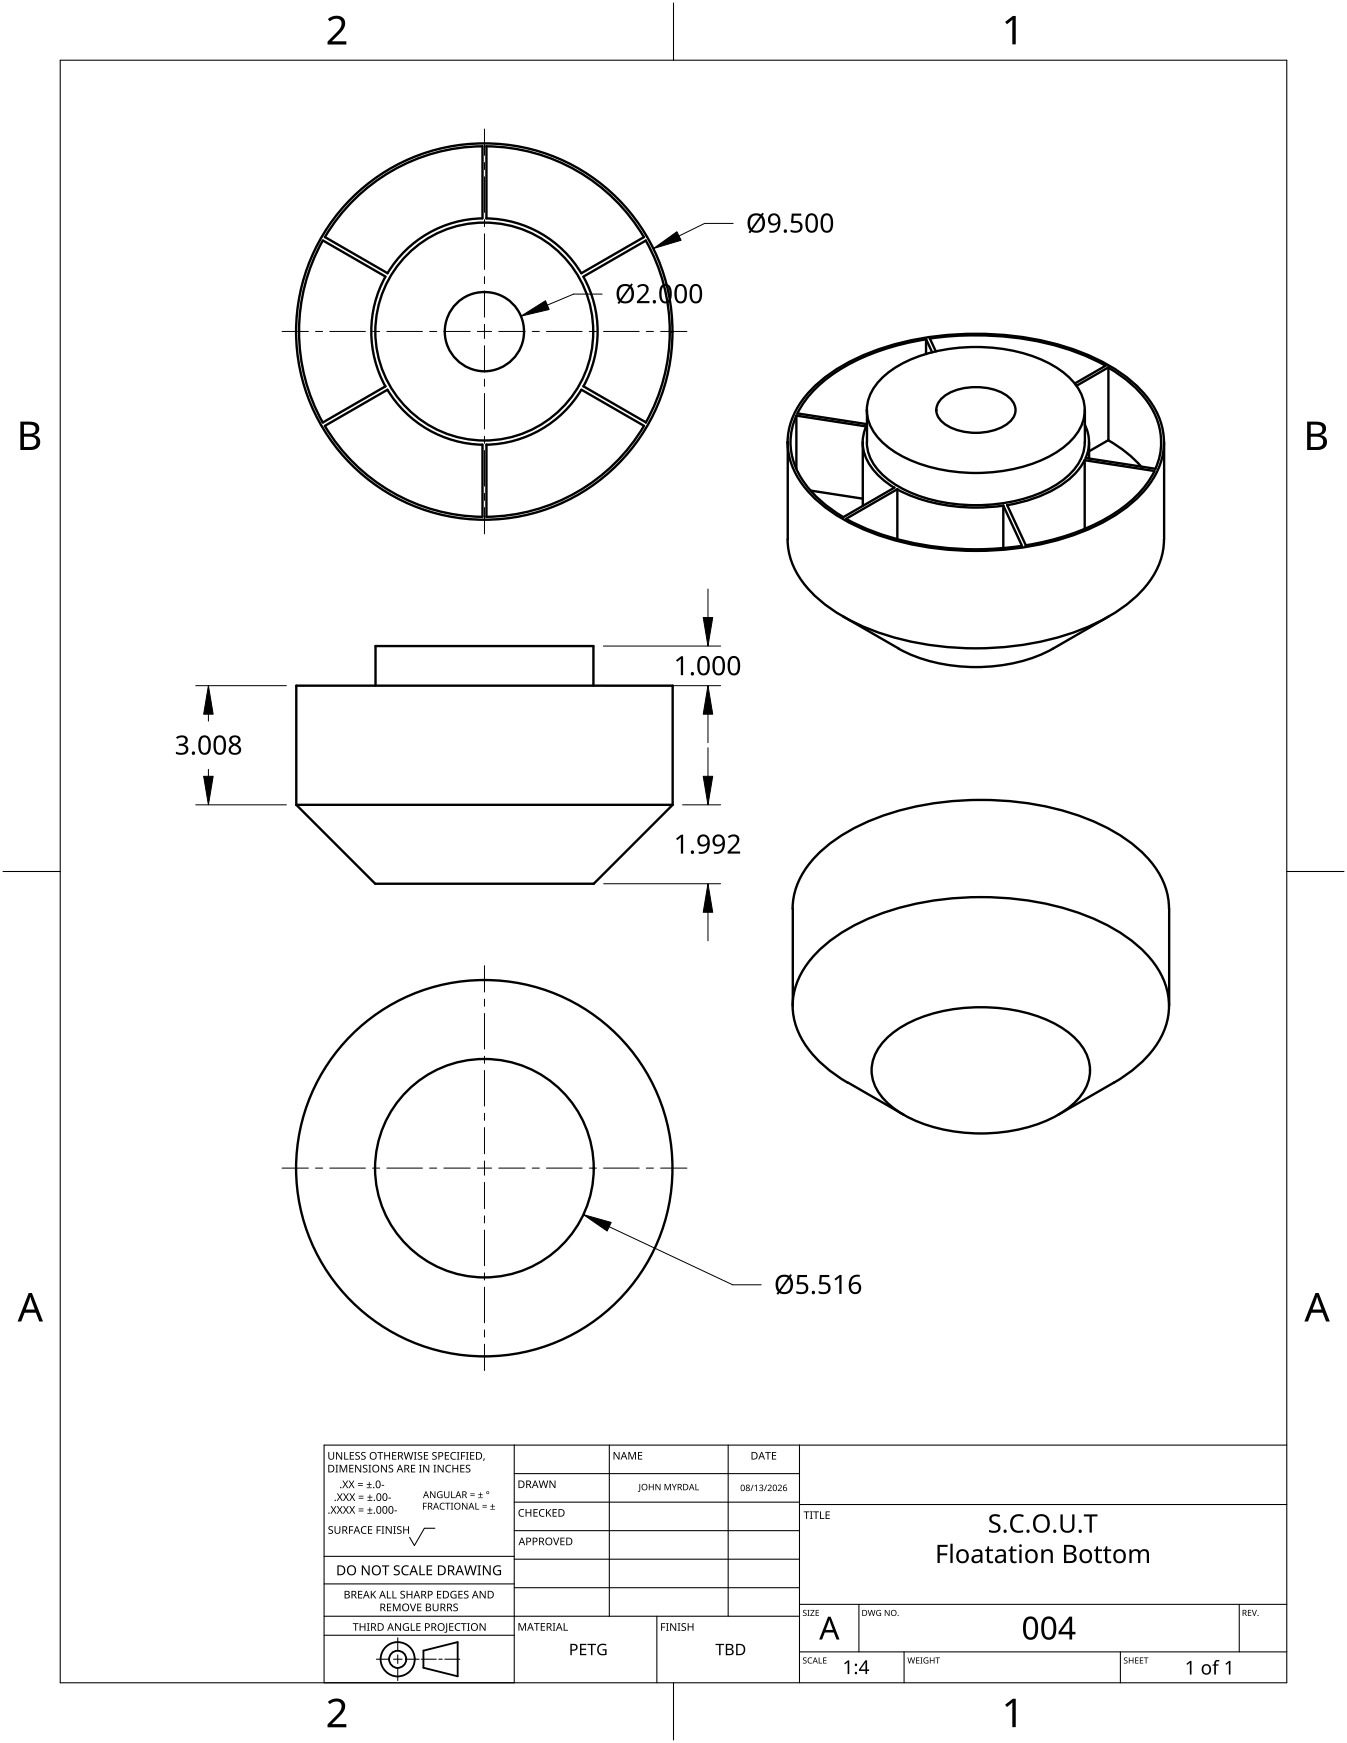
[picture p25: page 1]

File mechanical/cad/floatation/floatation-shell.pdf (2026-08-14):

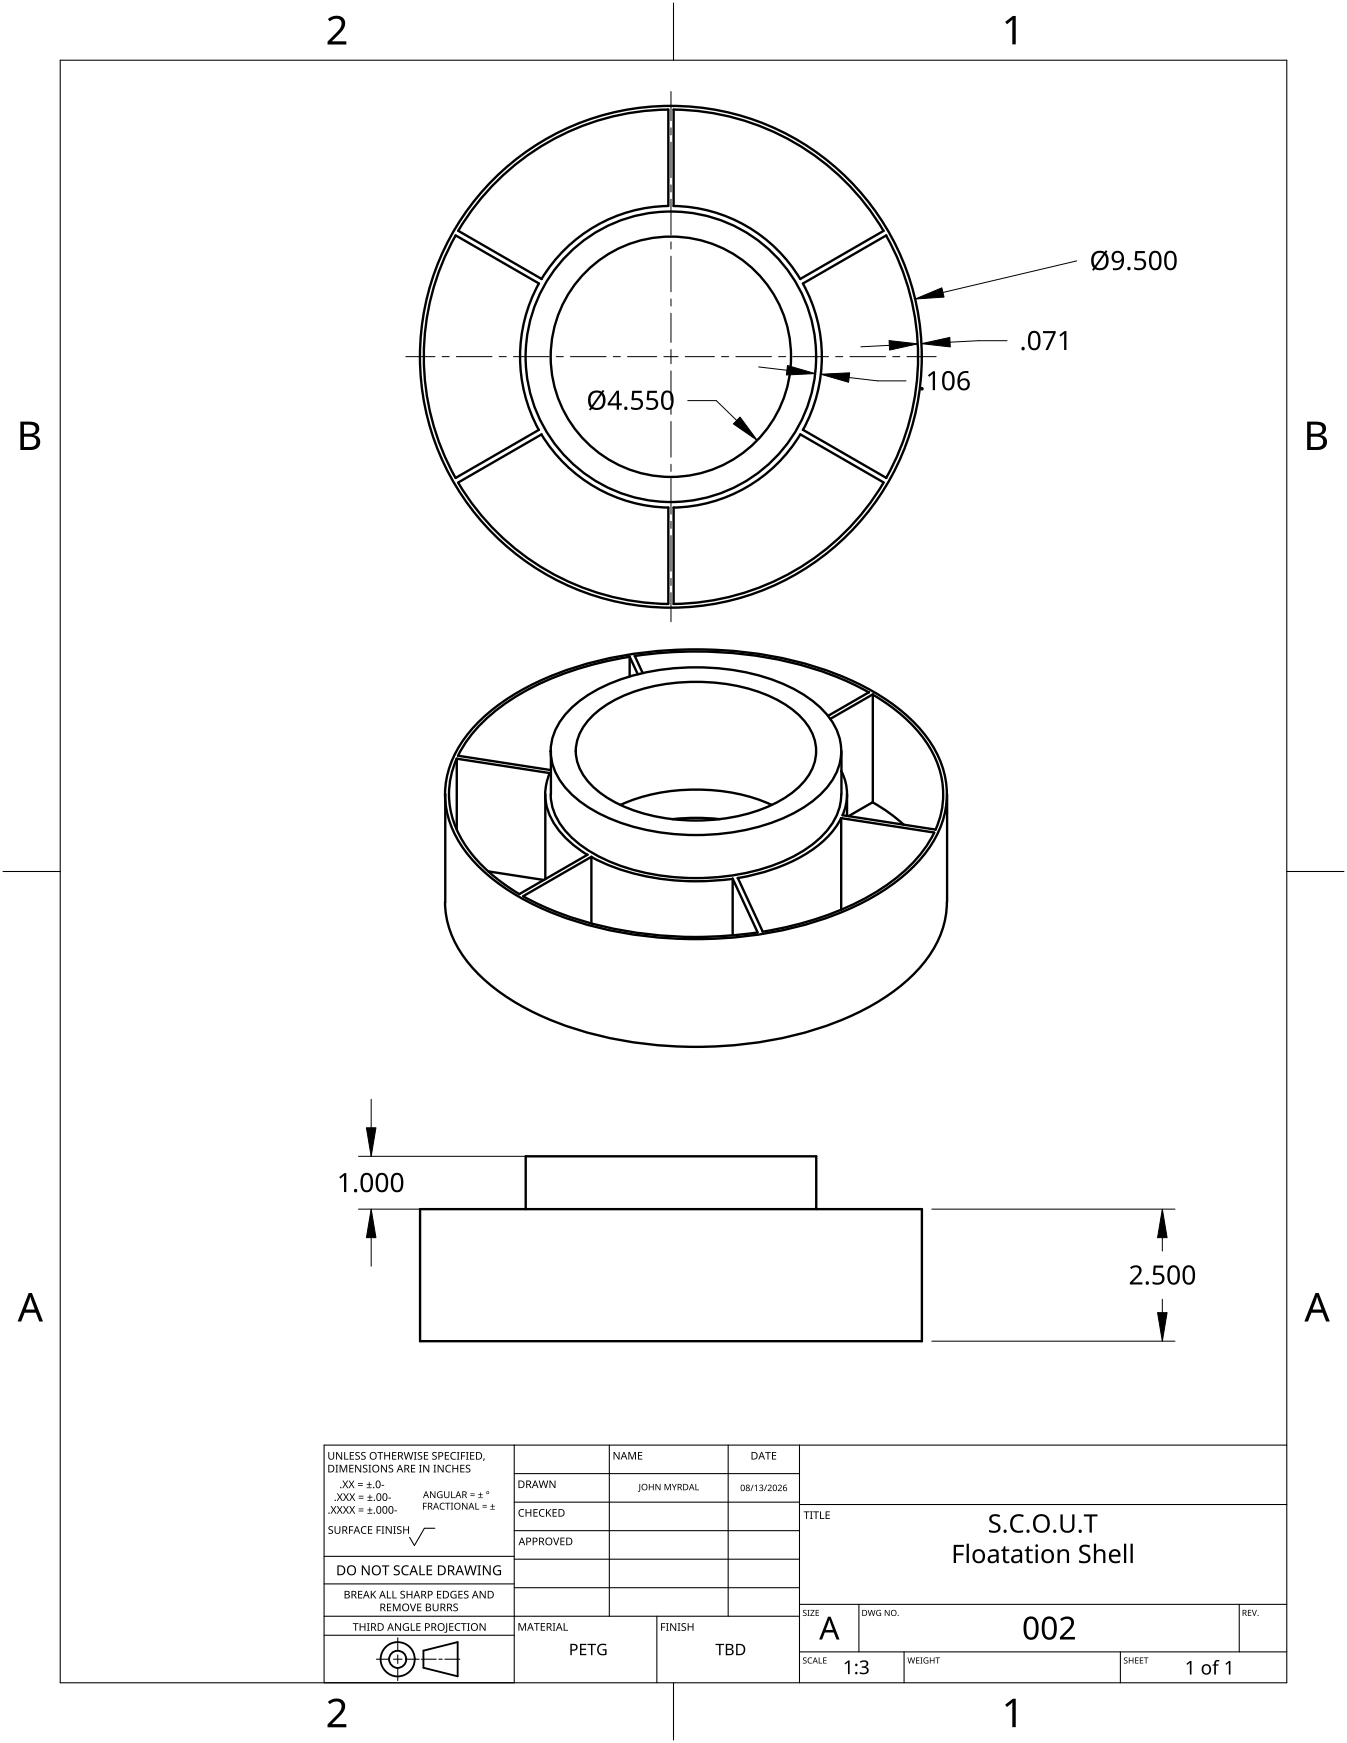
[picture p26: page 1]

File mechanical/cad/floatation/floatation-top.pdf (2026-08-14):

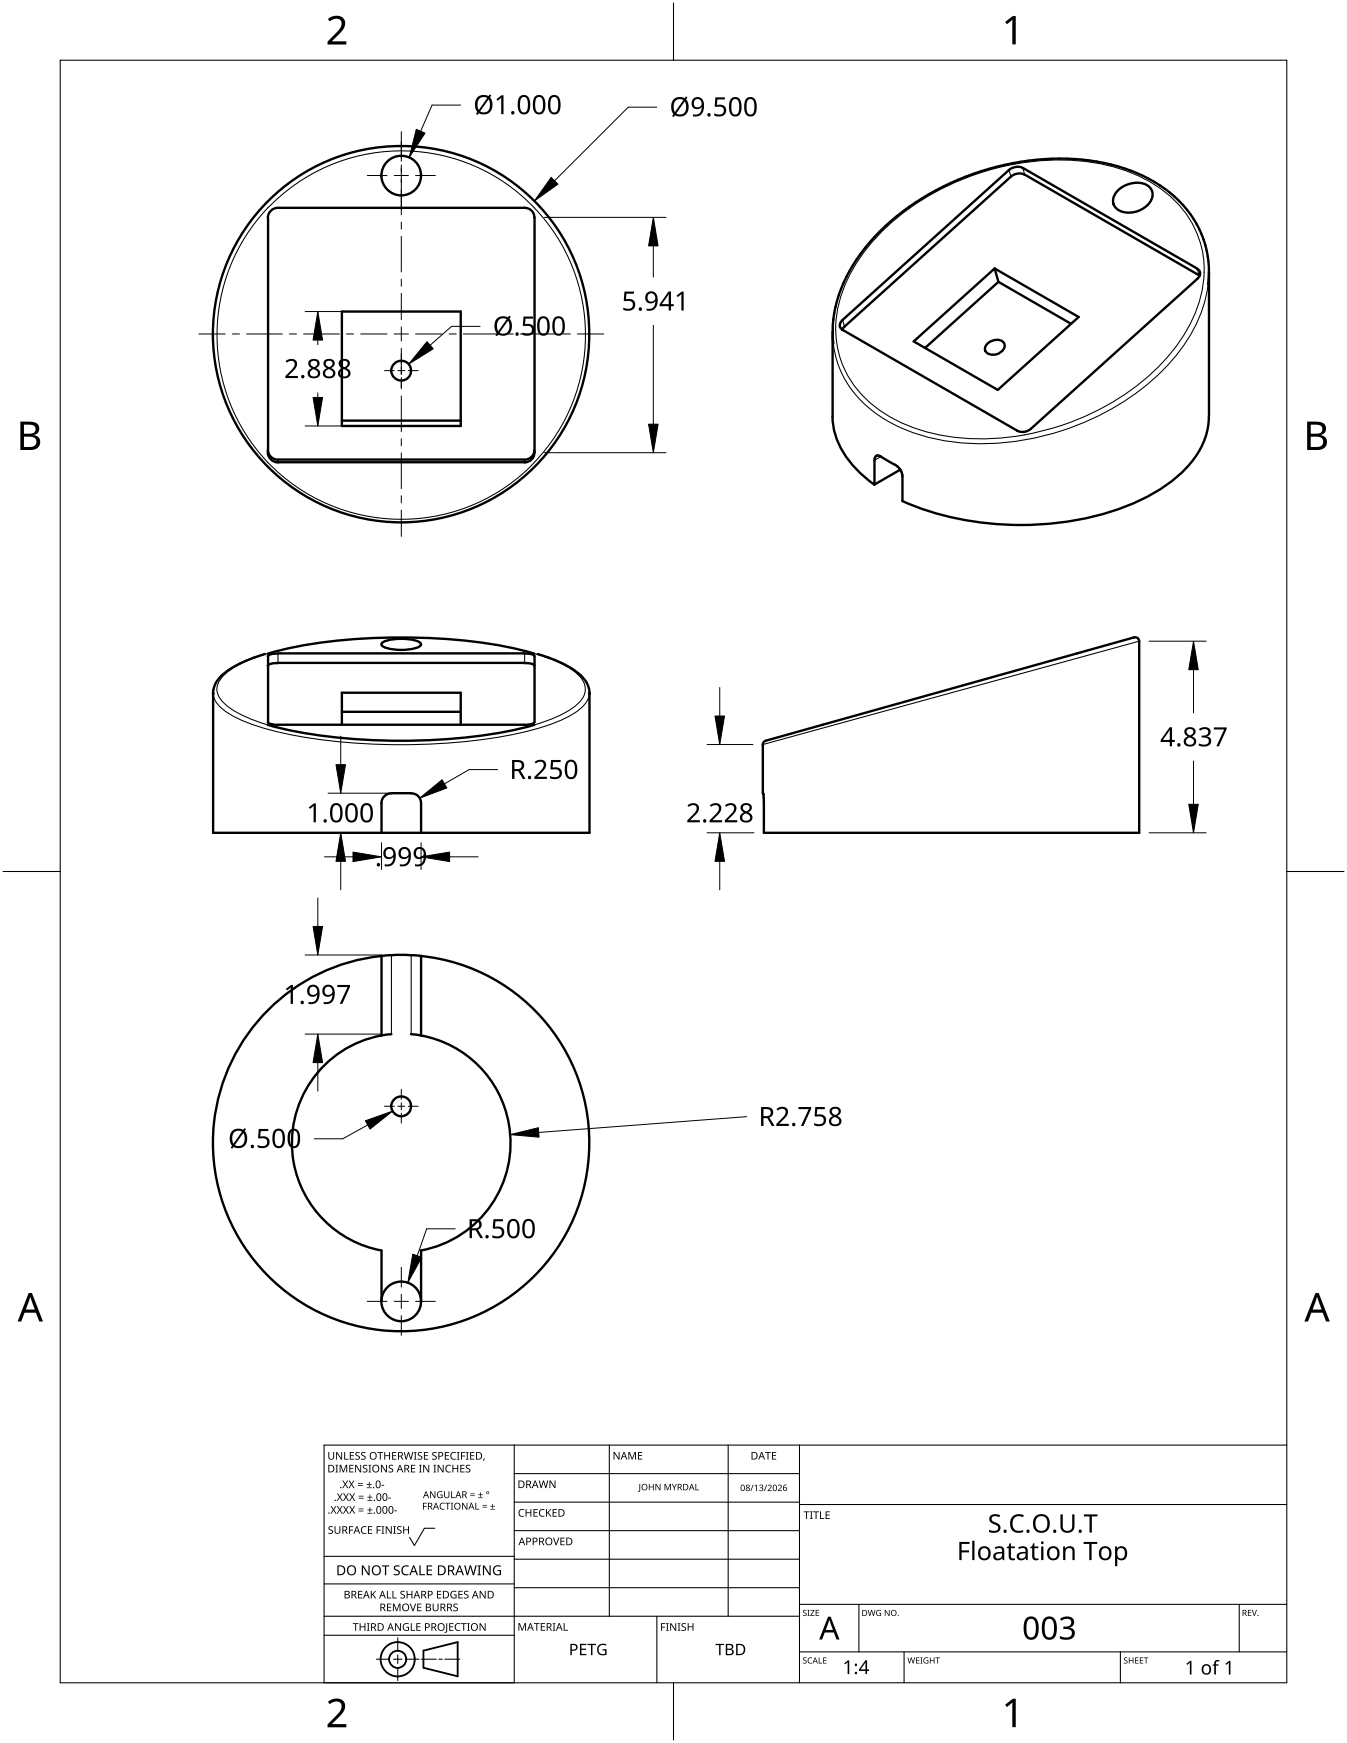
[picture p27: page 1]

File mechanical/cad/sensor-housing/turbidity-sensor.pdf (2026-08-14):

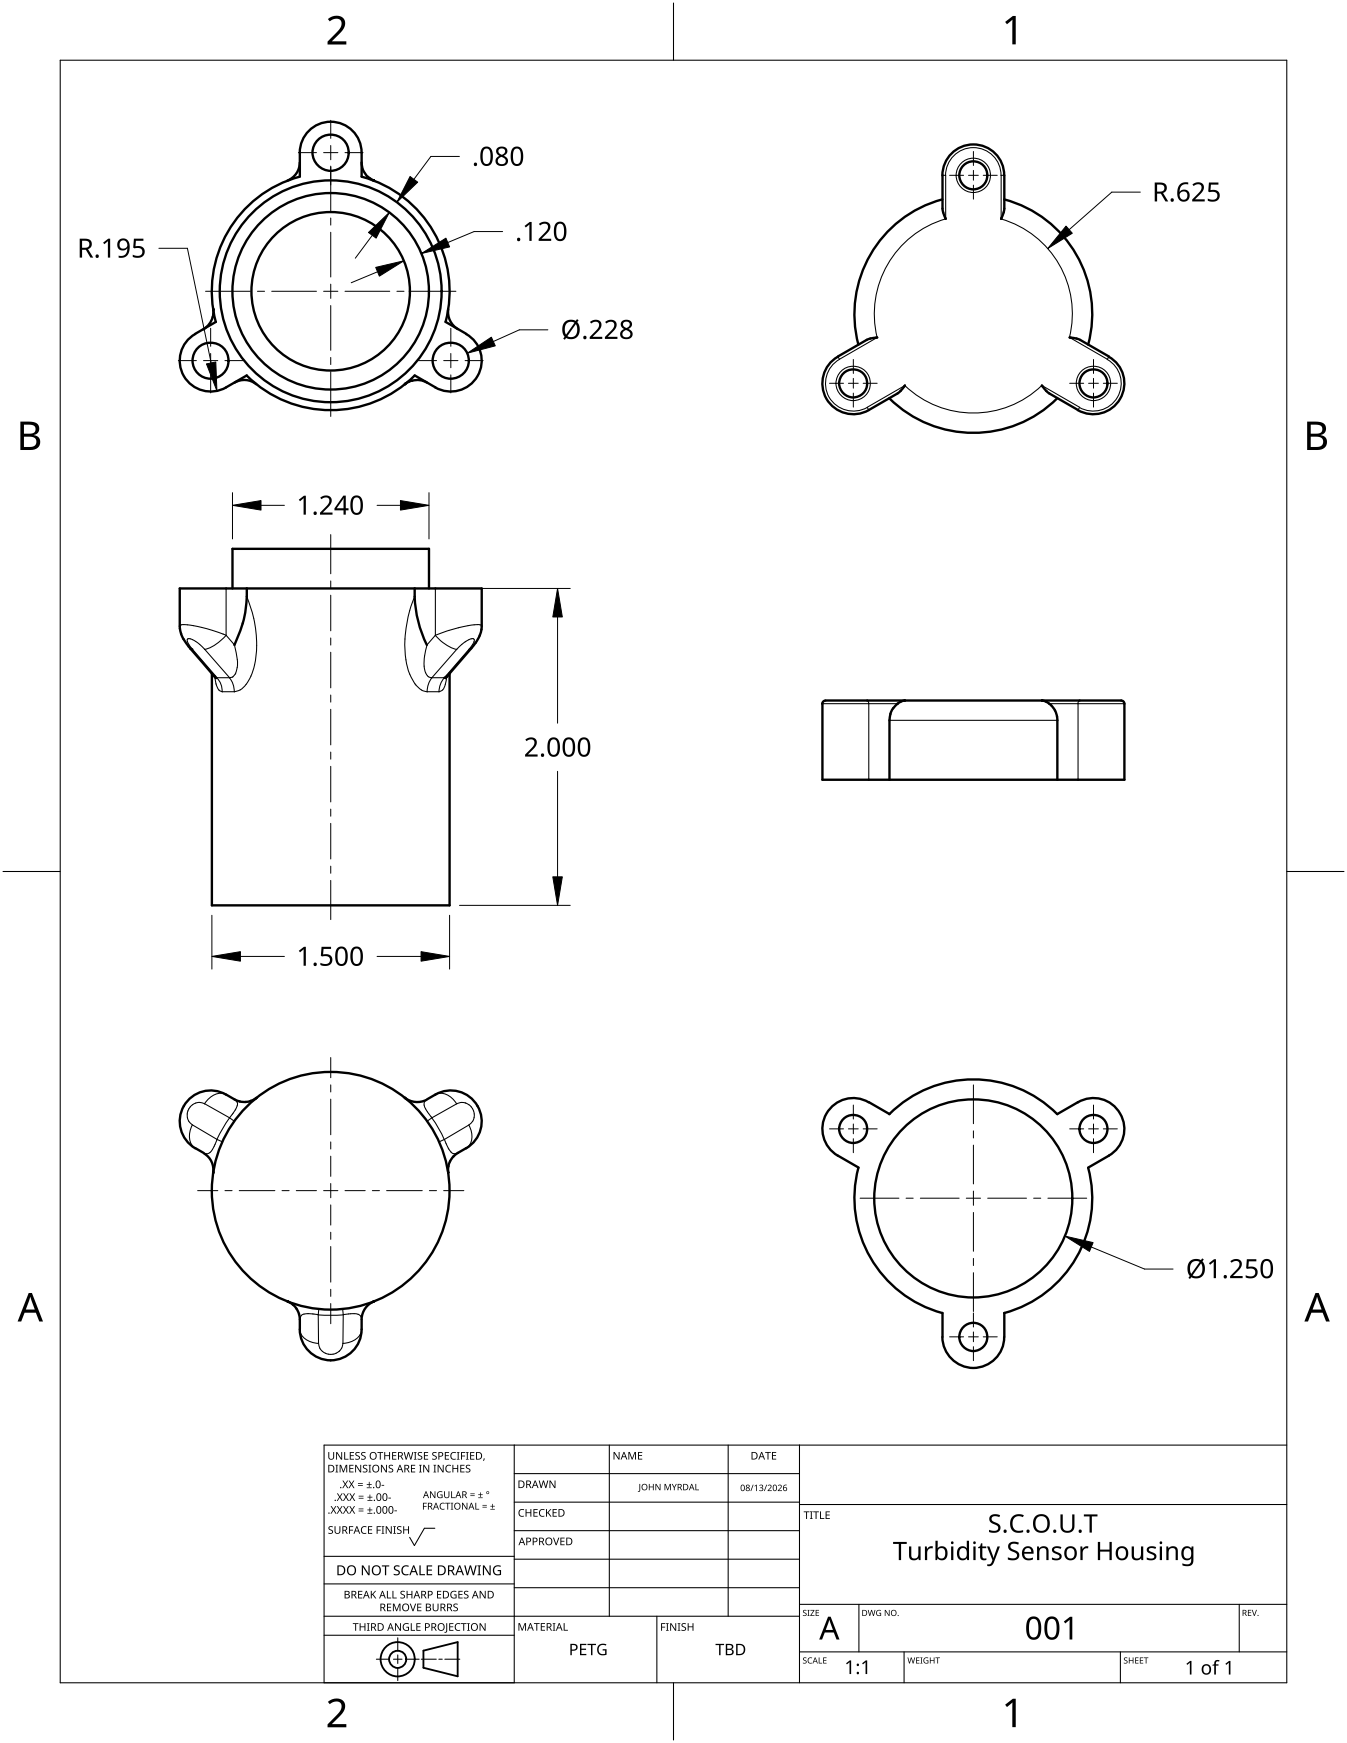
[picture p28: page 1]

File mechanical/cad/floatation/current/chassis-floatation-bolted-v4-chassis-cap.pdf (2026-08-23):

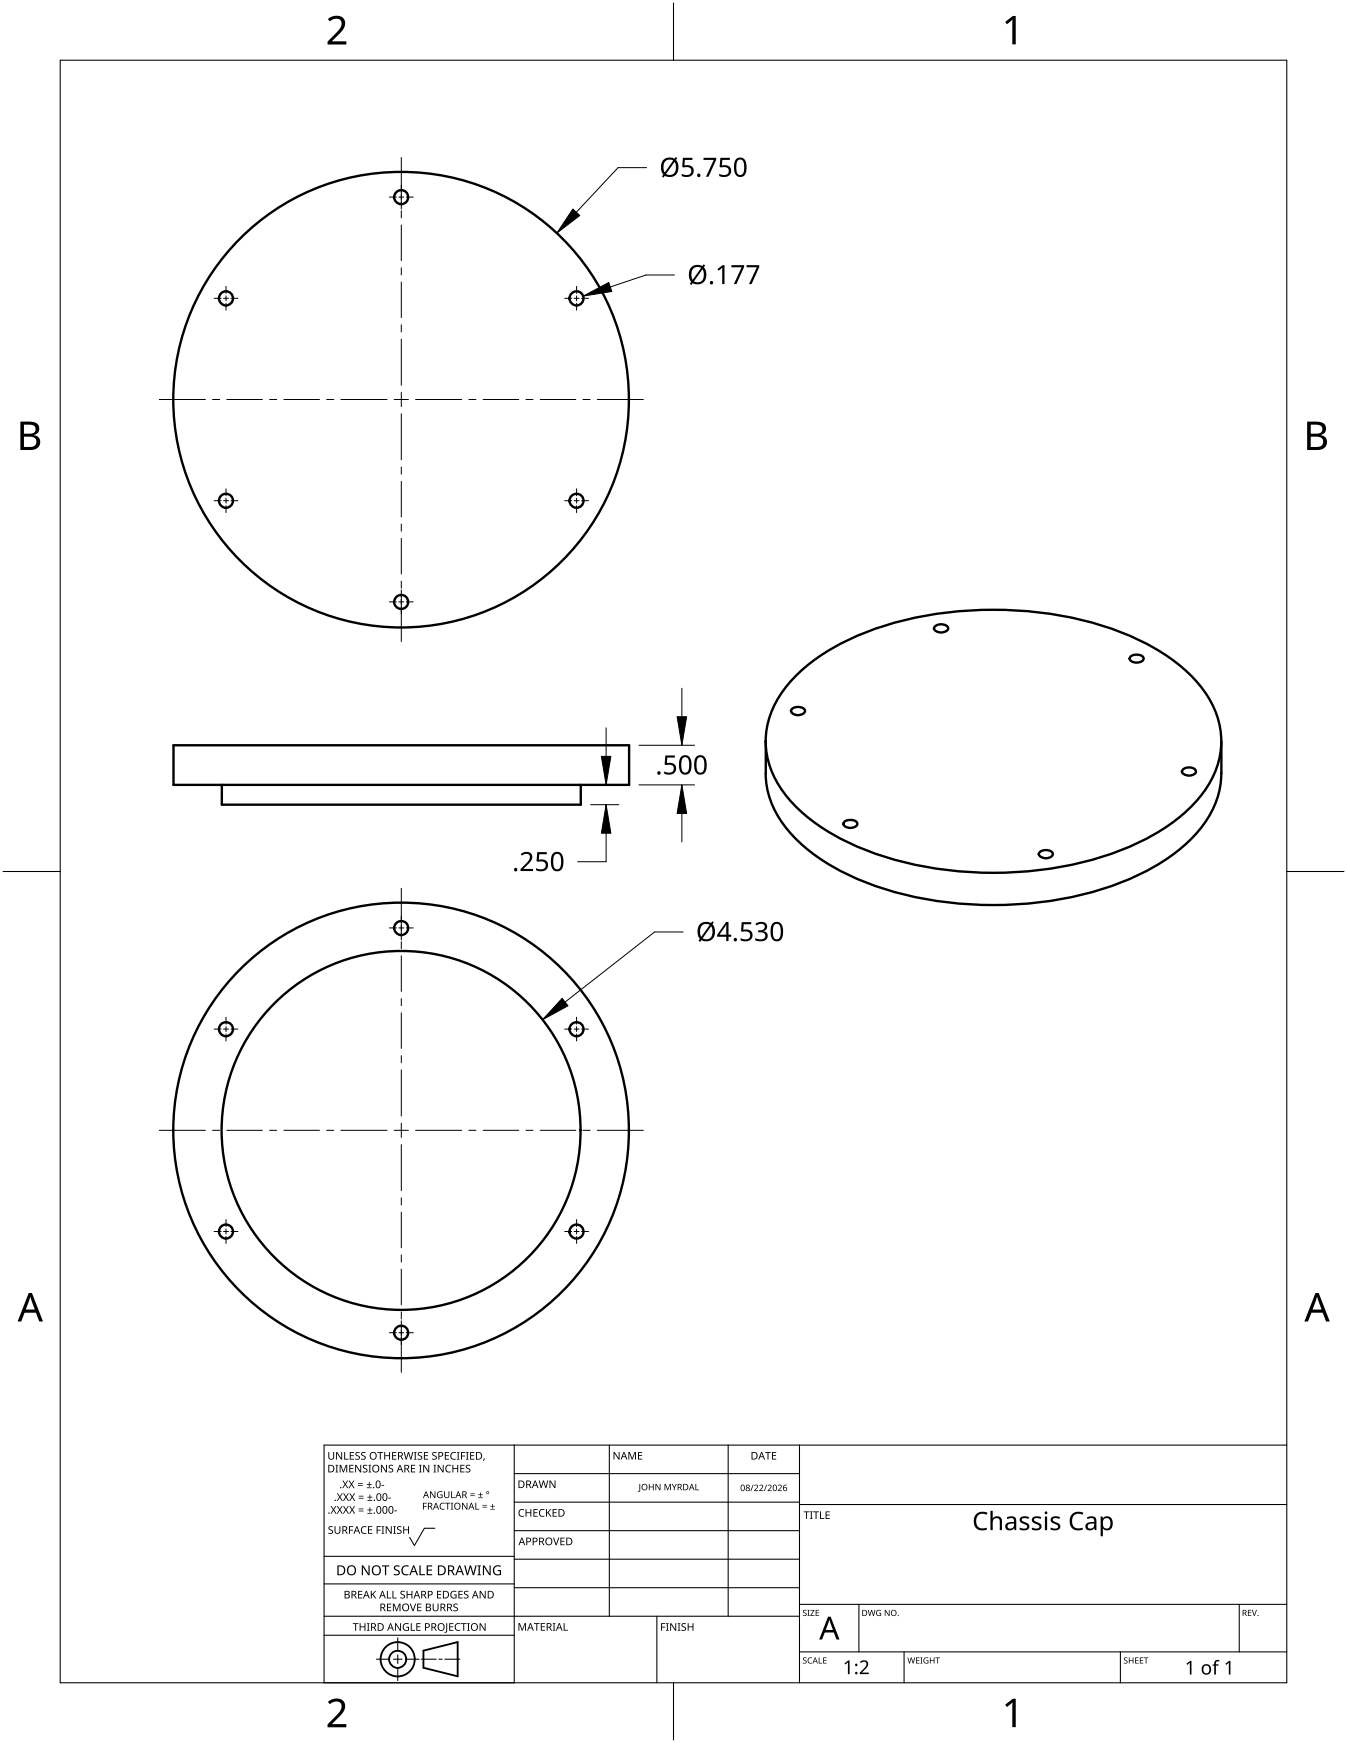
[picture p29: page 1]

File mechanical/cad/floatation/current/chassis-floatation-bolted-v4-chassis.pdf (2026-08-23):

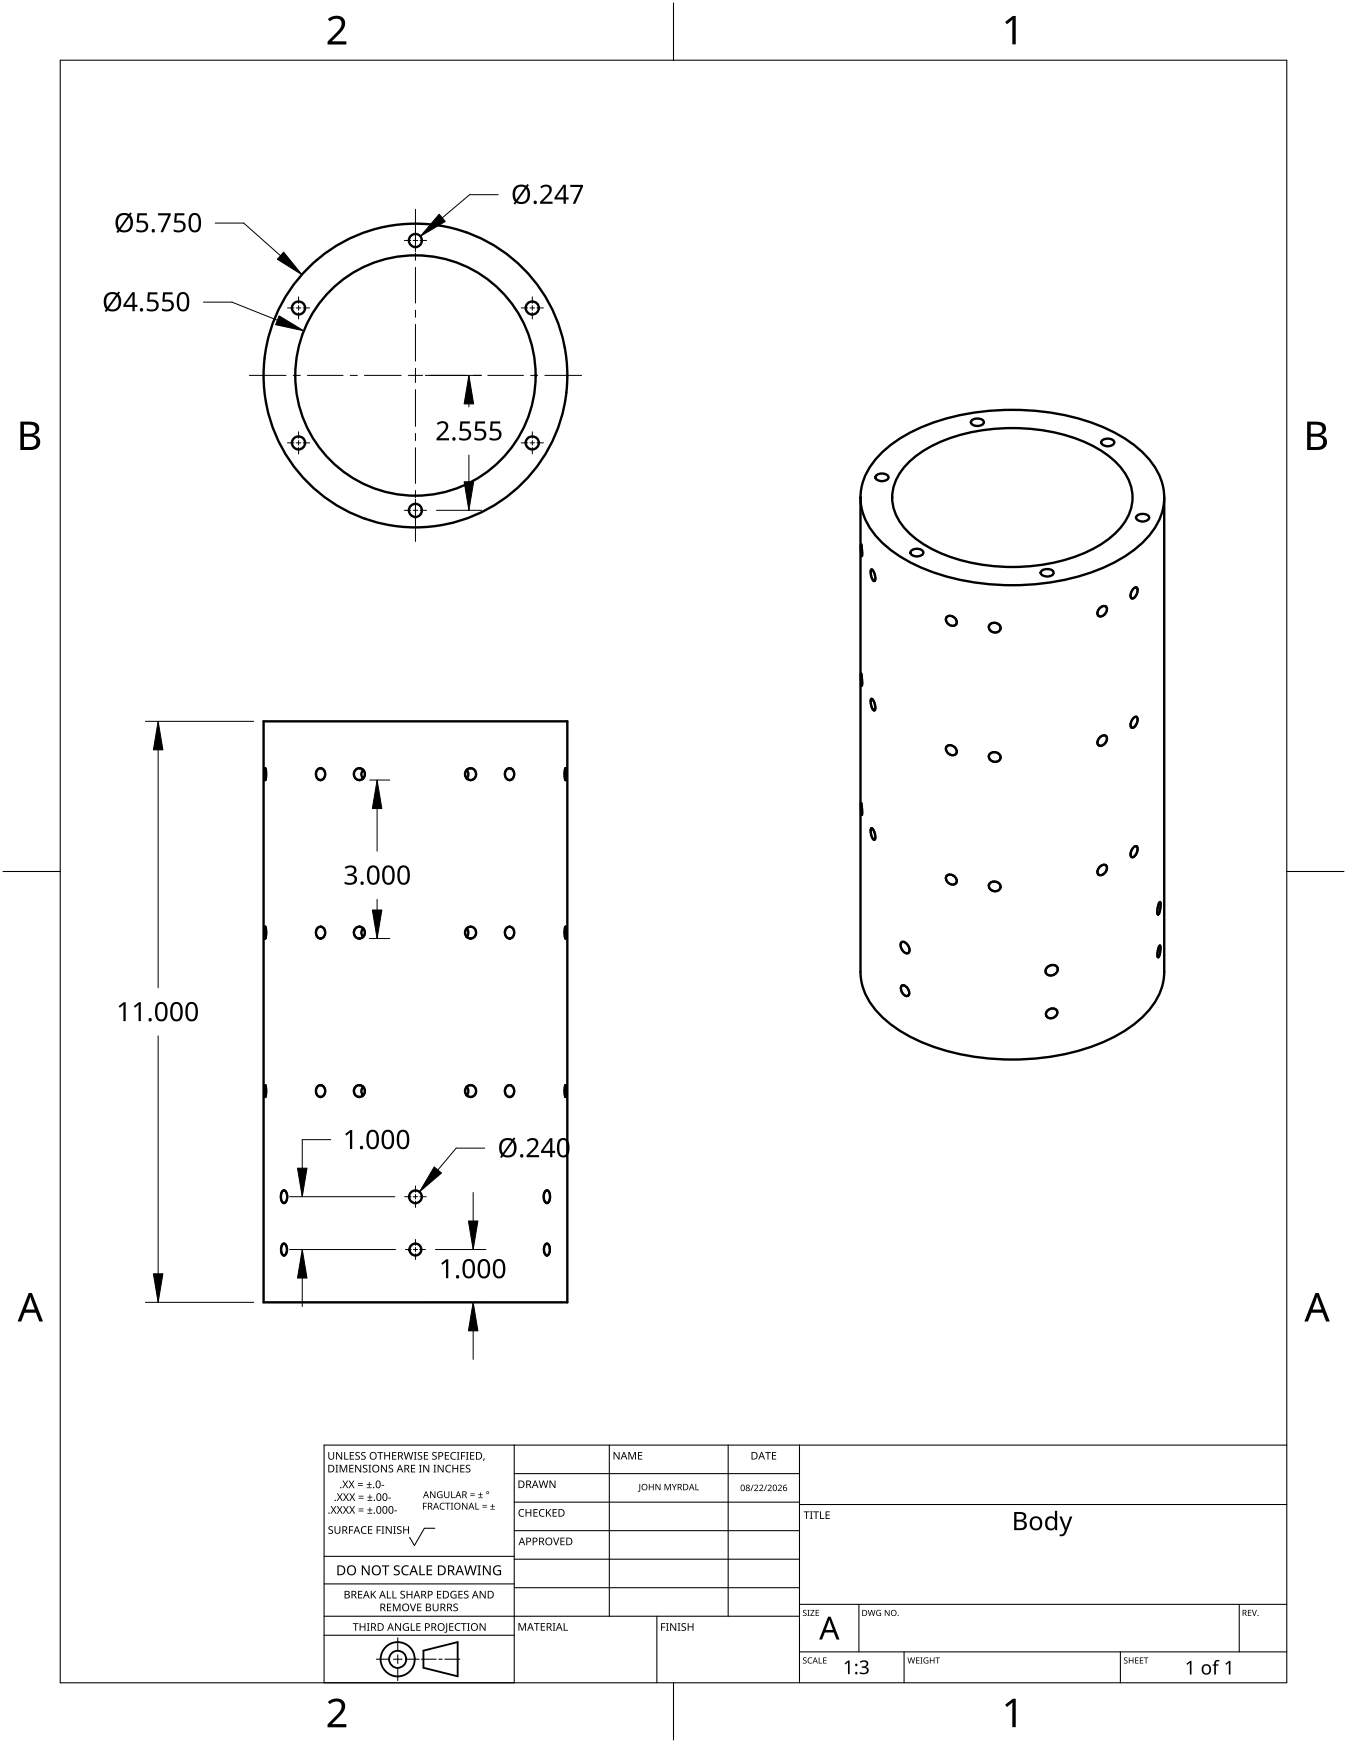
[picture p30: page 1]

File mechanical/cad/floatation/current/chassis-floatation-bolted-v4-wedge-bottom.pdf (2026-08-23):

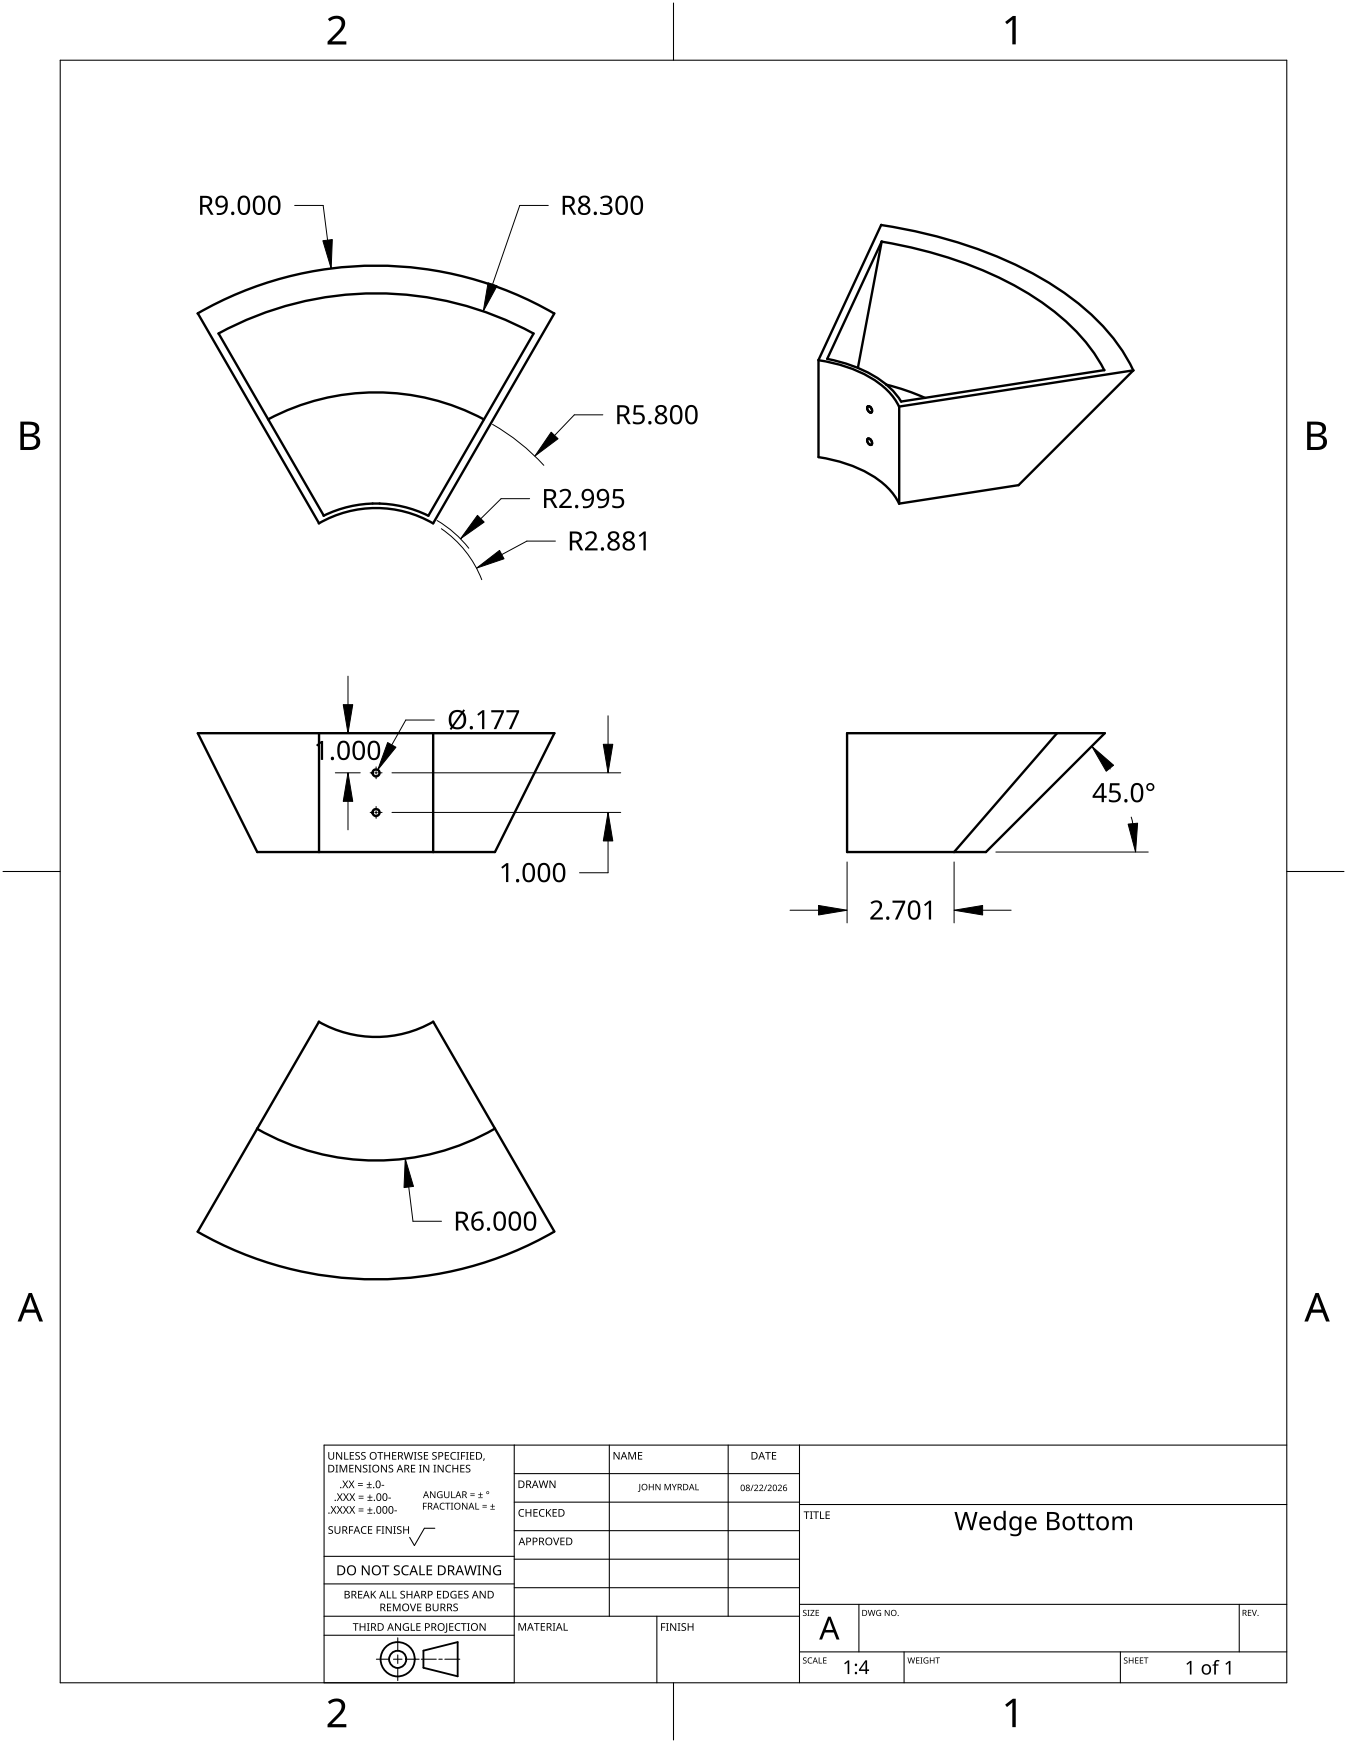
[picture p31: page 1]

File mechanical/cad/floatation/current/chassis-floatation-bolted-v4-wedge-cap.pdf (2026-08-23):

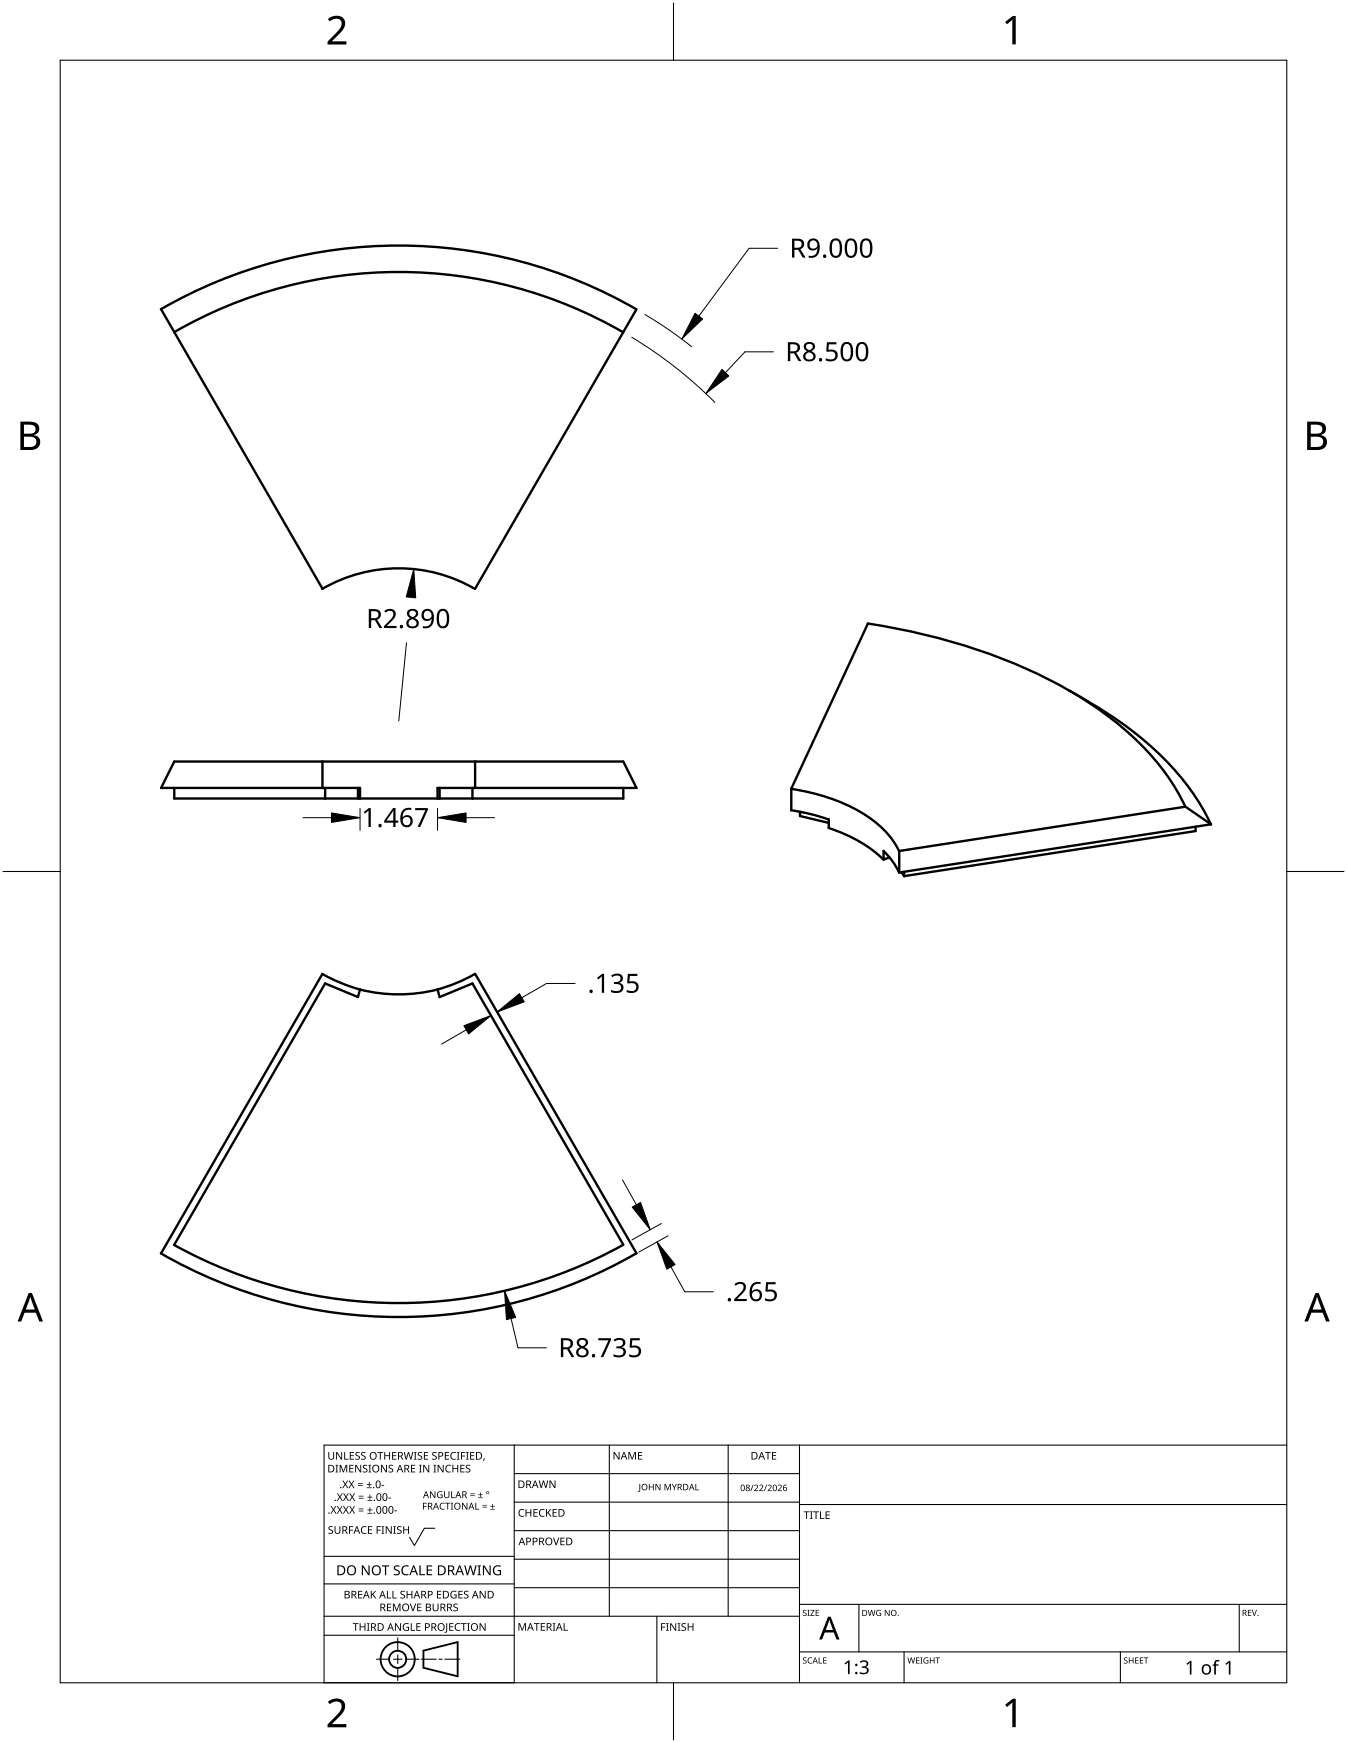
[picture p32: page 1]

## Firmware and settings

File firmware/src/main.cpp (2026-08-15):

/*
 * SCOUT buoy firmware — duty-cycle state machine.
 *
 *   Sleep → Wake → Sense → Log → Battery check → Transmit (daily) → Sleep
 *
 * Platform: Adafruit Feather M0 + RFM95 (SAMD21), Arduino core (ADR-0001).
 * The packet encoder (lib/scout_packet) mirrors the shore decoder byte-for-byte; the
 * scheduling math (lib/scout_scheduler) is pure and unit-tested off-target.
 *
 * Standby sleep (ArduinoLowPower + PCF8523 INT wake) and the watchdog are implemented;
 * record_seq/last_tx are retained across resets in a no-init RAM section. The audio subsystem
 * and on-hardware driver verification remain Phase 1–2 bring-up (see notes inline).
 */
#include <Adafruit_SleepyDog.h>
#include <Arduino.h>
#include <ArduinoLowPower.h>

#include "config.h"
#include "drivers/battery.h"
#include "drivers/lora_link.h"
#include "drivers/rtc.h"
#include "drivers/sd_logger.h"
#include "drivers/temperature.h"
#include "drivers/turbidity.h"
#include "scout_link.h"
#include "scout_packet.h"
#include "scout_scheduler.h"

static const char *CSV_HEADER =
    "schema_version,buoy_id,timestamp_utc,record_seq,temp_c,turbidity_adc,turbidity_v,"
    "turbidity_ntu,battery_v,uptime_s,audio_file,flags,soh,fw_version";

// Sequence counter and last-transmit time, kept in a NO-INIT RAM section that the C startup
// does not clear. They therefore survive a watchdog/system reset (the MCU stays powered), so
// record_seq stays monotonic and we don't re-send the daily packet after a reset. A magic
// guard tells real retained state from garbage on a cold power-on. This is RAM, so a full
// power loss still cold-starts — the PCF8523 has no user NVRAM to hold it, and we chose not
// to add SD/flash wear for the rarer power-loss case.
struct RetainedState {
    uint32_t magic;
    uint32_t record_seq;
    uint32_t last_tx_epoch;
};
static const uint32_t RETAINED_MAGIC = 0x5C002701u;
__attribute__((section(".noinit"))) static RetainedState g_state;

static TemperatureSensor g_temp;
static TurbiditySensor g_turbidity;
static Battery g_battery;
static ScoutRtc g_rtc;
static SdLogger g_sd;
static LoraLink g_lora;
static bool g_rtc_ok = false;
static bool g_sd_ok = false;
static bool g_lora_ok = false;
static bool g_watchdog_reset = false;  // set if the last reset was the watchdog firing
static uint8_t g_soh = 0;              // device State-of-Health bitfield, computed at boot

// ── flag-name formatting (matches the data-schema flags vocabulary) ──────────
static void append_flag(char *buf, size_t cap, bool &first, const char *name) {
    size_t len = strlen(buf);
    int written = snprintf(buf + len, cap - len, "%s%s", first ? "" : "|", name);
    if (written > 0) {
        first = false;
    }
}

static void format_flags(uint16_t flags, char *buf, size_t cap) {
    buf[0] = '\0';
    bool first = true;
    if (flags & SCOUT_FLAG_SD_RETRY) append_flag(buf, cap, first, "SD_RETRY");
    if (flags & SCOUT_FLAG_TEMP_TIMEOUT) append_flag(buf, cap, first, "TEMP_TIMEOUT");
    if (flags & SCOUT_FLAG_TURBIDITY_RANGE) append_flag(buf, cap, first, "TURBIDITY_RANGE");
    if (flags & SCOUT_FLAG_BATT_LOW_SKIP_TX) append_flag(buf, cap, first, "BATT_LOW_SKIP_TX");
    if (flags & SCOUT_FLAG_RTC_LOST) append_flag(buf, cap, first, "RTC_LOST");
    if (flags & SCOUT_FLAG_POWER_CONSERVE) append_flag(buf, cap, first, "POWER_CONSERVE");
}

static void format_soh(uint8_t soh, char *buf, size_t cap) {
    buf[0] = '\0';
    bool first = true;
    if (soh & SCOUT_SOH_WATCHDOG_RESET) append_flag(buf, cap, first, "WATCHDOG_RESET");
    if (soh & SCOUT_SOH_RTC_UNSET) append_flag(buf, cap, first, "RTC_UNSET");
    if (soh & SCOUT_SOH_SD_INIT_FAIL) append_flag(buf, cap, first, "SD_INIT_FAIL");
    if (soh & SCOUT_SOH_LORA_INIT_FAIL) append_flag(buf, cap, first, "LORA_INIT_FAIL");
}

// Wake ISR — the work happens back in loop() after deepSleep() returns; this just needs to
// exist for the wake source. Keep it trivial (no I2C/Serial from interrupt context).
static void on_rtc_wake() {}

static void enter_deep_sleep() {
    // The watchdog must be OFF during the 30-min standby, or it would reset us mid-sleep — its
    // max timeout (~16 s) is far shorter than the sample interval. It's re-armed at loop start.
    Watchdog.disable();
    g_lora.sleep();
    Serial.flush();
    // SAMD21 standby (~microamps) until the PCF8523 countdown-timer INT pulls PIN_RTC_INT low.
    // NOTE: USB/Serial drops during standby — expected in deployment; use the RTC cadence, not
    // the USB monitor, to confirm wake timing on the bench.
    LowPower.deepSleep();
    // Woke: release the timer flag so INT1 deasserts and the next interval can trigger.
    g_rtc.ackTimer();
}

void setup() {
    Serial.begin(115200);

    // Did the watchdog just reset us? (SAMD21 Power Manager reset-cause register.) Useful for
    // State-of-Health — a recurring watchdog reset means a cycle is hanging.
    // Read via the mask, not `RCAUSE.bit.WDT`: CMSIS defines `WDT` as a peripheral-pointer
    // macro, so the bitfield name is macro-expanded and the target build fails to compile.
    g_watchdog_reset = (PM->RCAUSE.reg & PM_RCAUSE_WDT) != 0;

    // Restore the retained counter/last-TX across a reset; cold-start them if the magic is
    // absent (fresh power-on → the no-init RAM holds garbage).
    bool warm_start = (g_state.magic == RETAINED_MAGIC);
    if (!warm_start) {
        g_state.magic = RETAINED_MAGIC;
        g_state.record_seq = 0;
        g_state.last_tx_epoch = 0;
    }

    // Guard initialization too — a hung driver init shouldn't brick the buoy. loop() re-arms
    // it each cycle and disables it before the long standby sleep.
    Watchdog.enable(WDT_TIMEOUT_MS);

    pinMode(PIN_SENSOR_GATE, OUTPUT);
    digitalWrite(PIN_SENSOR_GATE, LOW);

    g_battery.begin();
    g_temp.begin();
    g_turbidity.begin();

    g_rtc_ok = g_rtc.begin();
    uint16_t startup_flags = 0;
    if (!g_rtc_ok || g_rtc.lostPower()) {
        startup_flags |= SCOUT_FLAG_RTC_LOST;
    }
    if (g_rtc_ok) {
        g_rtc.enablePeriodicWake(SAMPLE_INTERVAL_MIN);
        // PCF8523 INT1 is open-drain, active-low → pull-up, wake on the falling edge.
        pinMode(PIN_RTC_INT, INPUT_PULLUP);
        LowPower.attachInterruptWakeup(PIN_RTC_INT, on_rtc_wake, FALLING);
        g_rtc.ackTimer();  // start from a clean flag
    }
    g_sd_ok = g_sd.begin();
    g_lora_ok = g_lora.begin();

    // Device State-of-Health snapshot (boot cause + subsystem init), sent in every packet/row.
    g_soh = 0;
    if (g_watchdog_reset) g_soh |= SCOUT_SOH_WATCHDOG_RESET;
    if (!g_rtc_ok || g_rtc.lostPower()) g_soh |= SCOUT_SOH_RTC_UNSET;
    if (!g_sd_ok) g_soh |= SCOUT_SOH_SD_INIT_FAIL;
    if (!g_lora_ok) g_soh |= SCOUT_SOH_LORA_INIT_FAIL;

    Serial.print("boot: watchdog_reset=");
    Serial.print(g_watchdog_reset ? "yes" : "no");
    Serial.print(" rtc=");
    Serial.print(g_rtc_ok ? "ok" : "FAIL");
    Serial.print(" sd=");
    Serial.print(g_sd_ok ? "ok" : "FAIL");
    Serial.print(" lora=");
    Serial.print(g_lora_ok ? "ok" : "FAIL");
    Serial.print(warm_start ? " start=warm resume_seq=" : " start=cold resume_seq=");
    Serial.println(g_state.record_seq);
    (void)startup_flags;  // folded into the first record below
}

void loop() {
    // Re-arm the watchdog for this cycle (it was disabled for the standby sleep). If any step
    // below hangs past WDT_TIMEOUT_MS, the buoy resets and recovers on its own.
    Watchdog.enable(WDT_TIMEOUT_MS);

    uint16_t flags = 0;
    uint32_t now = g_rtc_ok ? g_rtc.nowEpoch() : 0;
    if (!g_rtc_ok) {
        flags |= SCOUT_FLAG_RTC_LOST;
    }

    // 1. Power the switched sensor rail and let it settle.
    digitalWrite(PIN_SENSOR_GATE, HIGH);
    delay(SENSOR_WARMUP_MS);

    // 2. Sense. Read the battery first so the power mode can gate the rest (graceful
    //    degradation: NORMAL → CONSERVE → CRITICAL as the pack drains).
    uint16_t battery_mv = g_battery.readMillivolts();
    scout_power_mode_t mode = scout_power_mode(battery_mv, BATTERY_CONSERVE_MV, BATTERY_CRITICAL_MV);

    float temp_c = 0.0f;  // core signal — always sampled, even in CRITICAL
    if (!g_temp.read(temp_c)) {
        flags |= SCOUT_FLAG_TEMP_TIMEOUT;
    }

    bool turbidity_sampled = scout_sense_turbidity(mode);  // paused in CRITICAL
    uint16_t turbidity_adc = 0;
    float turbidity_v = 0.0f;
    if (turbidity_sampled) {
        turbidity_adc = g_turbidity.readAdc();
        turbidity_v = g_turbidity.readVolts();
    }

    // 3. Sensors off.
    digitalWrite(PIN_SENSOR_GATE, LOW);

    // 4. Audio: only when scheduled AND power allows (NORMAL only). PCM1808/hydrophone is a
    //    V1 stretch not on the confirmed build; this records the intent.
    bool audio_present =
        scout_should_record_audio(now, AUDIO_HOURS_UTC, sizeof(AUDIO_HOURS_UTC)) &&
        scout_sense_audio(mode);

    // 5. Power-mode flags, set before logging so the CSV row captures them.
    if (mode == SCOUT_POWER_CRITICAL) {
        flags |= SCOUT_FLAG_BATT_LOW_SKIP_TX;
    } else if (mode == SCOUT_POWER_CONSERVE) {
        flags |= SCOUT_FLAG_POWER_CONSERVE;
    }

    g_state.record_seq++;

    // 6. Log a CSV row (data-schema.md). Retry once on SD failure.
    char timestamp[24];
    if (g_rtc_ok) {
        DateTime dt((uint32_t)now);
        snprintf(timestamp, sizeof(timestamp), "%04u-%02u-%02uT%02u:%02u:%02uZ", dt.year(),
                 dt.month(), dt.day(), dt.hour(), dt.minute(), dt.second());
    } else {
        snprintf(timestamp, sizeof(timestamp), "1970-01-01T00:00:00Z");
    }
    char audio_file[20] = "";
    if (audio_present) {
        snprintf(audio_file, sizeof(audio_file), "%02u%02u%02uZ.wav",
                 (unsigned)((now % 86400) / 3600), (unsigned)((now % 3600) / 60), 0u);
    }

    char flag_str[80];
    format_flags(flags, flag_str, sizeof(flag_str));
    char soh_str[80];
    format_soh(g_soh, soh_str, sizeof(soh_str));

    // Turbidity columns are blank when the sensor was paused for power (CRITICAL mode).
    char turb_adc_s[8] = "";
    char turb_v_s[12] = "";
    if (turbidity_sampled) {
        snprintf(turb_adc_s, sizeof(turb_adc_s), "%u", turbidity_adc);
        snprintf(turb_v_s, sizeof(turb_v_s), "%.3f", turbidity_v);
    }

    char line[224];
    snprintf(line, sizeof(line),
             "%u,SCOUT-%02u,%s,%lu,%.2f,%s,%s,,%.2f,%lu,%s,%s,%s,v%d.%d.%d",
             SCOUT_PACKET_VERSION, (unsigned)BUOY_ID, timestamp, (unsigned long)g_state.record_seq,
             temp_c, turb_adc_s, turb_v_s, battery_mv / 1000.0f,
             (unsigned long)(g_state.record_seq * SAMPLE_INTERVAL_S), audio_file, flag_str, soh_str,
             FW_MAJOR, FW_MINOR, FW_PATCH);

    if (g_sd_ok) {
        char date_ymd[9];
        if (g_rtc_ok) {
            DateTime dt((uint32_t)now);
            snprintf(date_ymd, sizeof(date_ymd), "%04u%02u%02u", dt.year(), dt.month(), dt.day());
        } else {
            snprintf(date_ymd, sizeof(date_ymd), "19700101");
        }
        if (!g_sd.appendLine(date_ymd, CSV_HEADER, line)) {
            flags |= SCOUT_FLAG_SD_RETRY;
            g_sd.appendLine(date_ymd, CSV_HEADER, line);  // one retry
        }
    }

    // Pet the watchdog before the slowest step (LoRa TX blocks up to ~2 s).
    Watchdog.reset();

    // 7. Transmit — throttled by power mode (base period in NORMAL, ×factor in CONSERVE),
    //    and never in CRITICAL. The power-mode flags were set in step 5.
    uint32_t tx_period = scout_transmit_period_s(mode, TRANSMIT_PERIOD_S, TRANSMIT_CONSERVE_FACTOR);
    if (mode != SCOUT_POWER_CRITICAL && g_lora_ok &&
        scout_is_transmit_cycle(now, g_state.last_tx_epoch, tx_period)) {
        ScoutReading r;
        r.schema_version = SCOUT_PACKET_VERSION;
        r.buoy_id = BUOY_ID;
        r.timestamp = now;
        r.record_seq = g_state.record_seq;
        r.temp_c_centi = scout_temp_centi(temp_c);
        r.turbidity_adc = turbidity_adc;
        r.battery_mv = battery_mv;
        r.uptime_s = g_state.record_seq * SAMPLE_INTERVAL_S;
        r.flags = flags;
        r.soh = g_soh;
        r.audio_present = audio_present ? 1 : 0;
        r.fw_major = FW_MAJOR;
        r.fw_minor = FW_MINOR;
        r.fw_patch = FW_PATCH;

        uint8_t packet[SCOUT_PACKET_SIZE];
        size_t n = scout_packet_encode(&r, packet);

        // Blind repetition (lib/scout_link): send the same frame a few times, spaced, and
        // never listen for an ACK. A lost daily packet costs timeliness, not data — the full
        // record is on the SD card — so ACKed retransmit would buy little and risk an
        // avalanche across a multi-buoy deployment. The shore station deduplicates on
        // (buoy_id, record_seq), so the copies collapse to one row.
        uint8_t copies = scout_link_repeat_count(mode, SCOUT_LINK_REPEATS_NORMAL,
                                                 SCOUT_LINK_REPEATS_CONSERVE);
        bool any_sent = false;
        for (uint8_t i = 0; i < copies; i++) {
            if (g_lora.send(packet, (uint8_t)n)) {
                any_sent = true;
            }
            // Pet before the gap, not after: the watchdog must not expire while we wait.
            // scout_link_fits_watchdog asserts this policy leaves 2x headroom.
            Watchdog.reset();
            if (i + 1 < copies) {
                delay(scout_link_repeat_delay_ms((uint8_t)(i + 1),
                                                 SCOUT_LINK_REPEAT_BASE_DELAY_MS));
                Watchdog.reset();
            }
        }
        // Advance only if at least one copy reached the air; otherwise retry next cycle.
        if (any_sent) {
            g_state.last_tx_epoch = now;
        }
    }

    const char *mode_str = mode == SCOUT_POWER_NORMAL ? "NORMAL"
                           : mode == SCOUT_POWER_CONSERVE ? "CONSERVE"
                                                          : "CRITICAL";
    Serial.print("seq=");
    Serial.print(g_state.record_seq);
    Serial.print(" mode=");
    Serial.print(mode_str);
    Serial.print(" flags=");
    Serial.print(flag_str[0] ? flag_str : "-");
    Serial.print(" soh=");
    Serial.println(soh_str[0] ? soh_str : "-");

    // 8. Back to sleep until the next scheduled wake.
    enter_deep_sleep();
}

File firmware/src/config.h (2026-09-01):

/*
 * config.h — build-time configuration: pin map, cadence, thresholds.
 *
 * ⚠️ Pin numbers below are the Feather M0 + RFM95 + Adalogger defaults and MUST be confirmed
 * against the ECE lead's GPIO assignment table (Team Timeline Phase 0) before wiring.
 */
#ifndef SCOUT_CONFIG_H
#define SCOUT_CONFIG_H

#include <stdint.h>

/* ── Identity ─────────────────────────────────────────────────────────────── */
static const uint16_t BUOY_ID = 1;  // CSV/label renders as SCOUT-01
#define FW_MAJOR 0
#define FW_MINOR 1
#define FW_PATCH 0

/* ── Cadence (seconds) ────────────────────────────────────────────────────── */
static const uint32_t SAMPLE_INTERVAL_S = 1800;         // 30-minute duty cycle
static const uint8_t SAMPLE_INTERVAL_MIN = 30;          // for the PCF8523 countdown timer
static const uint32_t TRANSMIT_PERIOD_S = 86400;        // one LoRa packet per day (EDD §10)
static const uint8_t AUDIO_HOURS_UTC[] = {0, 8, 16};    // 3 recordings/day (EDD §9)
static const uint16_t SENSOR_WARMUP_MS = 500;           // turbidity settle after power-on
static const uint16_t WDT_TIMEOUT_MS = 16384;           // watchdog reset if a cycle hangs
                                                        // (SAMD21 max; a healthy cycle is a few s)

/* ── Power thresholds (adaptive/graceful-degradation tiers) ───────────────────
 * NORMAL   ≥ CONSERVE_MV            all sensing, transmit each interval
 * CONSERVE CRITICAL_MV..CONSERVE_MV skip audio, transmit every Nth interval
 * CRITICAL < CRITICAL_MV           temperature + logging only; no TX, turbidity, or audio
 * Provisional millivolts — depend on the final battery/charging path (ADR-0002). */
static const uint16_t BATTERY_CONSERVE_MV = 3200;                  // drop into conserve below this
static const uint16_t BATTERY_CRITICAL_MV = 3100;                  // drop into critical below this
static const uint32_t TRANSMIT_CONSERVE_FACTOR = 3;                // conserve: transmit ×3 less often

/* ── Pin map (Feather M0 defaults — confirm with ECE) ─────────────────────── */
#define PIN_ONEWIRE 12     // DS18B20 data (4.7 kΩ pull-up to 3.3 V)
#define PIN_TURBIDITY A1    // SEN0189 analog out (through level-safe front end — see ADR-0002)
#define PIN_SENSOR_GATE 11  // MOSFET gate: HIGH powers the switched sensor rail
#define PIN_BATTERY A7      // Feather M0 onboard 2:1 battery divider
#define PIN_SD_CS 10        // Adalogger microSD chip-select
#define PIN_RFM95_CS 8      // Feather M0 RFM95 defaults
#define PIN_RFM95_RST 4
#define PIN_RFM95_INT 3
#define PIN_RTC_INT 5       // PCF8523 INT1 → wake the MCU from standby (wire on the Adalogger)

/* ── Radio ────────────────────────────────────────────────────────────────── */
static const float LORA_FREQUENCY_MHZ = 915.0f;  // US ISM (902–928 MHz)
/* +11 dBm, NOT the +14 dBm the EDD §2 assumed.
 *
 * The RFM95 module on the Feather M0 (PID 3178) carries a Single Modular Approval,
 * FCC ID 2ASEORFM95C (Shenzhen HOPE Microelectronics), and that grant certifies a
 * conducted output power of 0.0145 W = 11.6 dBm. FCC modular-approval rules require the
 * integrator to keep RF output power and transmission parameters within the certified
 * limits; exceeding them invalidates the grant and pushes the end product into full
 * intentional-radiator certification. +14 dBm was ~2.4 dB over. 11 leaves margin.
 *
 * Cost is 3 dB of link budget, against the 6.5 dB the BW500/SF12 change gained — so the
 * radio is still ~3.5 dB better off than the +14 dBm BW125/SF7 configuration it replaced,
 * and now inside the grant rather than outside it on two counts.
 *
 * ANTENNA CONSTRAINT, recorded here because it is easy to violate by accident: the grant
 * was tested with a 2.15 dBi whip, and permits "only those antennas tested with the device
 * or similar antennas with equal or lesser gain". A higher-gain antenna to chase range —
 * the obvious lever if SCO-14's over-water test disappoints — VOIDS the modular approval.
 * The same applies to the shore station if it uses this module. */
static const int8_t LORA_TX_POWER_DBM = 11;
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

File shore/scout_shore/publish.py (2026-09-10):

"""Which telemetry the published dashboard is built from — real data, or the simulator.

The GitHub Pages workflow rebuilds the public dashboard hourly. Until the buoy is live there
is nothing real to show, so it generates 30 days of simulated telemetry and labels the page
with a sample-data banner. That is fine *only* while no real data exists.

The failure this module prevents: the workflow had no branch in it. It regenerated the
simulator's output every run, unconditionally. The first time the shore station landed real
CSVs in the repo, the next scheduled run — within the hour, with no human involved — would
rebuild the site from simulated readings and stamp them "not a live deployment". No error, no
failed check, no diff to notice. The dashboard would simply stop showing the deployment while
continuing to look healthy, which is the worst shape a data bug can take.

So the choice is made here, once, and tested:

- **Real data present** → publish it, with no sample banner.
- **No real data** → run the simulator into its *own* directory and label the result.

The two directories are deliberately separate. ``data-live/`` is tracked and is where received
CSVs land; ``data/`` is gitignored scratch for loopback and demo runs. The regeneration step
targets the scratch directory by construction, so it has no path to overwrite real readings
even if this logic were bypassed.

Standard library only — this runs in CI and on a bare Raspberry Pi.
"""

from __future__ import annotations

from dataclasses import dataclass
from pathlib import Path

# Shown atop the dashboard when the numbers came from the simulator. Real data gets no banner:
# a live deployment labelled "simulated" misleads exactly the reader the page exists for.
SAMPLE_BANNER = (
    "Sample data: simulated telemetry for demonstration, not a live deployment."
)

# Where the shore station's received CSVs land. Tracked in git, unlike the scratch directory.
LIVE_DIR = Path("shore/data-live")
# Loopback and demo output. Gitignored; safe to clobber on every CI run.
SAMPLE_DIR = Path("shore/data")


@dataclass(frozen=True)
class SourceChoice:
    """What the dashboard build should read, and how the page should describe it."""

    source: Path
    simulate: bool  # run the simulator first? Never true when real data was found.
    banner: str | None  # None means "say nothing" — the data speaks for itself.

    def as_github_output(self) -> str:
        """Render as ``key=value`` lines for ``$GITHUB_OUTPUT``.

        ``simulate`` is lowercased because Actions compares step outputs as strings: a
        Python ``True`` would render as ``True`` and ``== 'true'`` would never match, which
        would silently skip the generate step and build the site from an empty directory.
        """
        banner = self.banner or ""
        # A newline here would end the `banner=` line early and let the remainder be parsed as
        # further step outputs — a corrupted build at best, output injection at worst. Nothing
        # today produces one; this refuses to be the reason a future edit does it silently.
        if "\n" in banner or "\r" in banner:
            raise ValueError("banner must be a single line to be a safe GitHub Actions output")
        return (
            f"source={self.source}\n"
            f"simulate={'true' if self.simulate else 'false'}\n"
            f"banner={banner}\n"
        )


def has_telemetry(directory: Path) -> bool:
    """True when this directory holds at least one telemetry CSV.

    Checked by content, not by existence: the live directory is committed with a ``.gitkeep``
    and a README so the path survives a clone, and neither of those makes the buoy live.
    """
    if not directory.is_dir():
        return False
    return any(directory.glob("*.csv"))


def select_source(
    *,
    live_dir: Path = LIVE_DIR,
    sample_dir: Path = SAMPLE_DIR,
) -> SourceChoice:
    """Decide what the published dashboard is built from.

    Real data always wins. There is no flag to override that, because every reason to publish
    the simulator over a live deployment is a mistake.
    """
    if has_telemetry(live_dir):
        return SourceChoice(source=live_dir, simulate=False, banner=None)
    return SourceChoice(source=sample_dir, simulate=True, banner=SAMPLE_BANNER)


def main() -> None:
    """Print the choice as ``$GITHUB_OUTPUT`` lines. Used by the Pages workflow."""
    import argparse

    parser = argparse.ArgumentParser(description=__doc__.splitlines()[0])
    parser.add_argument("--live-dir", type=Path, default=LIVE_DIR)
    parser.add_argument("--sample-dir", type=Path, default=SAMPLE_DIR)
    args = parser.parse_args()
    print(select_source(live_dir=args.live_dir, sample_dir=args.sample_dir).as_github_output(), end="")


if __name__ == "__main__":
    main()

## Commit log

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2026-08-14 docs: add CLAUDE.md project operating manual
    Shared contract for how the team works across GitHub, Linear, Notion, and
    Granola. Read automatically at the start of every Claude session pointed at
    this repo.
    Defines the session-start alignment check, artifact routing (one home per
    artifact type), and conventions for Linear issues, Notion pages, Granola
    meeting follow-up, and commits. Records repo gotchas: the pre-bash hook that
    blocks 'git push origin main', the absent gh CLI, and the WAV commit ban.
    States plainly that Granola has no MCP connector, so meeting content must be
    pasted in by a human rather than assumed readable.
2026-08-14 docs: re-baseline project timeline to Aug 2026 - May 2027
    The original plan ran Phases 0-2 over summer 2026, but those deliverables did
    not complete (firmware never started), so every window was stale. Reset the
    full schedule across the remaining project duration.
    Phase 0 is now design-alignment only, covering the open decisions that were
    never closed. Phase 6 gets ~10 weeks of live deployment so there is real data
    to analyze before the final presentation, with the Hawaii trip landing near
    spring break.
    Linear phase projects and issue due dates mirror these dates.
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2026-08-14 docs: resolve ADR-0001 (Feather M0 build platform) and reframe SCOUT as a monitoring platform
    Adopt the dual-platform resolution from ADR-0001: Adafruit Feather M0 + RFM95
    (3178) + Adalogger FeatherWing (2922) is the confirmed build platform (Arduino
    SAMD21 / RadioHead RH_RF95); ESP32-C3 + SX1262 is retained as the future
    production-PCB target. This unblocks firmware and wiring.
    - ADR-0001 marked Accepted; open questions resolved (audio analyzed shore-side
    due to 32 KB SRAM; custom PCB out of capstone scope)
    - hardware/: confirmed-hardware + production-target tables, datasheet source index
    - firmware/: toolchain set to SAMD21, RTC corrected to PCF8523, blocker removed
    - team-timeline: Pha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
2026-08-14 docs: require all changes to reach main via a PR (title + description), never direct push
    Make the PR-only flow explicit where people look before pushing (Git intro,
    Branches, Pull requests, Two repo gotchas) and in CLAUDE.md standing rules, so
    nobody commits on main and gets rejected by the force-push hook before the PR
    step. Reconciles the old 'small doc fixes can go straight to main' line.
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2026-08-14 docs(engineering): define the on-board CSV data schema (v1)
    Phase 0 CS deliverable. Specifies the microSD log format the firmware writes
    and the shore station / analytics pipeline reads: one row per sample event,
    fixed column order, UTC ISO-8601 timestamps, units in column names, empty (not
    zero) for unsampled fields. Includes file layout, a flags vocabulary, an
    example, the LoRa-packet relationship, and open questions (turbidity units,
    ADC full-scale, depth-string count, SoH sensor). Links it from the docs index
    and firmware README.
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2026-08-14 docs: reconcile depth, LoRa range, academic year, and project name
    Resolve four audit inconsistencies:
    - Deployment depth = 5-8 m (MVP overview); ~30 m diagram label flagged outdated
    - LoRa range standardized to ~2 km line-of-sight, sourced to the Adafruit RFM9x
    range FAQ (~100 yd and 15-20 km figures corrected); real over-saltwater range
    still to be measured in Phase 4
    - Academic year = 2026-2027 (no stray 2025-2027 remained)
    - Project name = 'Oceanic Utilities' (plural), already consistent
    Updates MVP overview, EDD, meeting-notes, ADR-0001, sensor-string, mechanical
    README, and both inconsistency tables. Stacked on the single-point-sensing branch.
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2026-08-14 docs: add Knowledge Hub reading notes (thermal stress, LoRa range, turbidity ecology)
    Six literature reading notes for the research library:
    - liu-2014-dhw / skirving-2020-coraltemp-mmm — the NOAA CRW DHW + MMM basis for
    telemetry bleaching.py and the run_telemetry --mmm requirement
    - jovalekic-2018-lora-seawater / gutierrez-gomez-2021-lora-near-surface — the two
    ends of the LoRa-over-saltwater range envelope (22 km LOS upper bound vs.
    low-antenna path-loss reality) behind the ~2 km design figure
    - fabricius-2005-runoff / sully-2020-turbid-refugia — turbidity as an ecological
    stressor, and its sign-flipping interaction with heat stress (why temp+turbidity
    must not be summed a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
2026-08-14 ci(pages): GitHub Actions workflow to deploy the telemetry dashboard + sample-data banner
    Add .github/workflows/pages.yml: on push/schedule/dispatch it generates the dashboard
    from the shore simulator (stdlib only, no committed data) and deploys to GitHub Pages via
    actions/deploy-pages. Adds a --banner option (web.py/pipeline/run_telemetry) so the public
    sample deploy is clearly labeled 'SAMPLE DATA — simulated … not a live deployment.'
    Swap the generate step for real shore CSVs once the buoy is live. 40 telemetry tests pass.
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2026-08-14 feat(firmware): enable real SAMD21 standby sleep (ArduinoLowPower + PCF8523 INT wake)
    Replace the enter_deep_sleep() delay placeholder with true SAMD21 standby:
    - LowPower.deepSleep(), woken by the PCF8523 countdown-timer INT on PIN_RTC_INT
    (attachInterruptWakeup, FALLING; INPUT_PULLUP for the open-drain, active-low line)
    - Rtc::ackTimer() clears the Control_2 CTAF flag on wake so INT1 releases and the
    timer re-arms for the next interval (preserving the other Control_2 bits)
    - Serial.flush() before sleep; USB/Serial drops in standby (documented)
    Updates firmware README + flashing-guide. Needs bench verification: INT wiring and a
    current measurement to confirm the low-power draw.
    [main.cpp]
2026-08-14 feat(firmware): add watchdog timer for autonomous hang recovery (EDD §12)
    SAMD21 WDT via Adafruit_SleepyDog (16 s):
    - enabled in setup() to guard init and re-armed at the top of every loop()
    - petted before the slowest step (LoRa TX, ~2 s block)
    - DISABLED before standby sleep and re-armed on wake — its timeout is far shorter than the
    30-min interval, so it must not run during standby
    - boot detects a prior watchdog reset via PM->RCAUSE.bit.WDT and logs it (SoH signal)
    A hung sensor/SD/LoRa call now resets the buoy so it recovers unattended. Note: a reset
    restarts record_seq/last_tx (RAM) — acceptable for recovery; persist later if needed.
    [config.h, main.cpp]
2026-08-14 docs(hub): add Linear backlog staging doc
    Stages the Linear issues that still need creating in the scout1 workspace,
    written so a future session with Linear access can file them mechanically.
    Consolidates, with title/labels/owner/priority/project/acceptance for each:
    - A. Open decisions & blockers (Phase 0): LiFePO4 charging path (ADR-0002),
    hydrophone part number, dissolved-oxygen inclusion, turbidity units — the
    items status.md/facts.md/decision-log.md flag as "needs a Linear issue"
    - B. Research questions — mirror of research/open-questions.md (11 items)
    - C. Implementation follow-ups from the 17 merged PRs (shore radio bring-up,
    on-hardware driver validation, flag inconsistenc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
2026-08-14 feat(firmware): retain record_seq/last_tx across resets (no-init RAM)
    Close the duplicate-daily-TX edge from the watchdog work: record_seq and last_tx_epoch now
    live in a magic-guarded .noinit RAM section the C startup does not clear, so a watchdog/
    system reset keeps the counter monotonic and skips a redundant packet. Cold-starts on a full
    power loss (RAM-based; the PCF8523 has no user NVRAM, and SD/flash persistence was declined
    to avoid wear for the rarer power-loss case). Boot logs start=warm/cold + resume_seq.
    Correction: the PCF8523 has no battery-backed user RAM (unlike the DS1307), so 'RTC RAM' was
    not an option — retained SRAM achieves the same goal for the reset case.
    [main.cpp]
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2026-08-14 ci: add test workflow with cross-language packet-contract guard
    GitHub Actions CI on every push to main and every PR:
    - python-tests job: shore unittest suite + telemetry unittest suite (stdlib only, no deps)
    + scripts/check_packet_contract.py, which encodes the canonical reading with the shore
    encoder and asserts it equals the firmware Unity GOLDEN bytes — fails on any firmware↔shore
    wire drift (previously verified only by hand each packet change)
    - firmware-tests job: pio test -e native runs the packet + scheduler Unity suites on the host
    Adds a CI status badge to the README. The contract guard catches exactly the silent drift we
    kept re-checking manually across the SoH/format ch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
2026-08-14 feat(firmware): adaptive transmission (battery-tiered graceful degradation)
    Implement the MVP energy-resilience strategy as a battery-voltage power mode:
    - scout_scheduler: scout_power_mode() → NORMAL / CONSERVE / CRITICAL, plus
    scout_transmit_period_s() (base → ×factor → never) and scout_sense_turbidity/audio() gates.
    Pure logic, unit-tested (7 scheduler tests total).
    - config.h: BATTERY_CONSERVE_MV / BATTERY_CRITICAL_MV tiers + TRANSMIT_CONSERVE_FACTOR
    (replaces the single BATTERY_SKIP_TX_MV gate).
    - main.cpp: read battery first → derive mode → NORMAL all-sensing+daily-TX;
    CONSERVE drops audio and transmits ×3 less often; CRITICAL keeps only temperature+logging,
    no tu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
    [config.h, main.cpp, packet.py]
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2026-08-14 feat(analytics): light-only sandy theme + real Ocean Image Bank reef photos
    Make the site a single deliberate warm-sand (light) theme regardless of the OS
    colour-scheme — drop the dark-mode override, set color-scheme: light only, and
    a single sandy theme-color. Per request: the canvas is always beige/sand.
    Replace the four authored habitat atmospheres with real, credited photographs
    from the Ocean Image Bank (curated, centre-cropped to the pill 3:4, ~55 KB each,
    same-origin under assets/img/): shallow reef (Noemi Merz), soft-coral colony
    (Cinzia Osele Bismarck), kelp forest (Stefan Andrews), open water (Kurt Arrigo)
    — each shown with the licence-required "Photographer / Ocean Image Bank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
2026-08-15 fix(firmware): make the Feather M0 target build compile, and guard it in CI
    The firmware has never compiled for its own target. CI runs only
    `pio test -e native`, which excludes src/ and never includes CMSIS, so
    three independent breakages reached main unnoticed:
    1. platformio.ini pinned `arduino-libraries/ArduinoLowPower`, but the
    registry ID carries spaces ("Arduino Low Power"), so dependency
    resolution failed before a single file was compiled.
    2. `class Rtc` in drivers/rtc.h collides with the `Rtc` union the SAMD21
    CMSIS device header defines for the MCU's own RTC peripheral, so every
    call through g_rtc failed to resolve. Renamed to ScoutRtc.
    3. `PM->RCAUSE.bit.WDT` expands t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
    [main.cpp]
2026-08-15 feat(firmware): CR 4/8 and blind repetition for the daily packet
    Closes the firmware half of SCO-21. A lost daily packet costs timeliness,
    not data — the full record is on the SD card — so the requirement is soft
    and ACKed retransmit is the wrong tool: it buys little and invites an
    avalanche once several buoys retry into the same congested window
    (carvalho-2021). Blind repetition costs the same whether the link is
    perfect or dead, which is what a solar-powered node wants.
    Repeats are spaced with widening gaps rather than sent back to back: at a
    sub-meter antenna over moving water, consecutive frames share one fade,
    which is the likeliest way to lose all of them. Count degrades with the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
    [main.cpp, receiver.py, store.py]
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2026-08-15 feat(mechanical): add floatation CAD iteration history (v1-v9)
    STEP exports for the flotation design arc: CNC/foam ring concept -> PETG
    3D-printed supports with injected foam and marine epoxy coating -> single-
    print sections (scaling problems) -> snap-fit multi-print assembly.
    Final selection not yet made; documented as iteration history in the
    folder README.
    [floatation-v1.step, floatation-v2.step, floatation-v3-snap-concept.step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]
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2026-08-15 fix(analytics): correct the SEN0189 turbidity polarity across the pipeline
    The DFRobot datasheet settles what SCO-16 left open: "Analog Signal
    Output, the output value will decrease when in liquids with a high
    turbidity", with clear water (<0.5 NTU) at ~4.1 V. The SEN0189 measures
    transmittance, and the firmware logs raw analogRead with no inversion, so
    a HIGHER turbidity_adc count means CLEARER water and a sediment plume is
    a dip, not a spike.
    Three places had assumed the opposite:
    - turbidity.py flagged positive excursions as "dirtier water", so it was
    reporting each day's clearest readings as sediment plumes — on a
    dashboard that is already public. Now flags negative excursions.
    -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
    [simulator.py]
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2026-08-16 feat(mechanical): add current electronics housing CAD
    Chassis-cylinder body and end cap (heat-set insert M4 bolts + washers,
    rubber sealing washers for waterproofing). Current cap has a shackle
    connection point as a placeholder; final design swaps that for a cable
    gland, matching the cable-entry method already in mechanical/README.
    [electronics-housing-body.step, electronics-housing-endcap-no-port.step]
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2026-08-16 feat(mechanical): add wedge-based floatation design and Outer Octagon
    Master V3 (chassis-floatation-integrated-v3): floatation wedges snap
    into keyholes with adjacent wedges, mechanically lock into the chassis
    cylinder, then get filled with expanding foam for structure/buoyancy/
    waterproofing, with epoxy as an additional pre-fastener. Master V3 Copy
    1 (chassis-floatation-bolted-v3): simpler variant, heat-set inserts and
    bolts alone, no snap keyholes. Each wedge is field-replaceable --
    maintenance advantage worth noting for lifecycle analysis.
    Outer Octagon (shell + bottom) is a confirmed-separate design, not
    derived from Master V3. Neither this nor the wedge design is yet
    declared final for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
    [chassis-floatation-bolted-v3-part1.step, chassis-floatation-bolted-v3-part2.step, chassis-floatation-integrated-v3-part1.step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]
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2026-08-17 fix(shore): correct stale 29-byte packet size to verified 30 bytes
    packet.py's docstring said 27-byte body + 2-byte CRC = 29 bytes, but
    _BODY_FORMAT computes 28 bytes and PACKET_SIZE evaluates to 30 --
    matching firmware's SCOUT_PACKET_SIZE and facts.md. The docstring and
    shore/README.md were never updated when the SoH byte was added (PR
    #22). Also drops the stale "pending ECE spec, reconcile before
    freezing" framing -- firmware/README.md already documents the codec
    as verified byte-identical via a CI-enforced golden vector test.
    Addresses part of SCO-40's acceptance criteria.
    [packet.py]
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2026-08-23 docs(mechanical): move current bolted-v4 design into its own subfolder
    mechanical/cad/floatation/ mixed the active design (chassis-floatation-
    bolted-v4-*, 5 STEP + 5 PDF pairs) flat with 24 files of superseded
    history (v1-v9, Outer Octagon, the pre-caps v3 bolted/integrated pass) --
    nothing in the folder itself signaled which files actually matter right
    now.
    Moves the v4 set (STEP + matching PDF together, not split) into
    current/, with a README note on what to do when a future design
    supersedes it. Updates every reference -- the floatation README's own
    prose (drawings list, "Files added" narrative) and the mass/buoyancy
    budget doc's source-drawings note -- and verifies each fixed link
    reso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
    [chassis-floatation-bolted-v4-chassis-cap.step, chassis-floatation-bolted-v4-chassis.step, chassis-floatation-bolted-v4-wedge-bottom.step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]
2026-08-24 docs(hardware): reconcile Rev A artifacts with current main
    Rebuild the Rev A schematic-verification work on top of current main
    instead of the stale base it was originally committed against. Carries
    forward the native KiCad schematic/project, exported PDF, interconnect
    SVG, and manufacturer datasheets unchanged from the prior branch. Merges
    new information into main's existing hardware/README.md rather than
    replacing it: preserves the dual-platform framing and confirmed-hardware
    table, adds a Rev A prototype schematic section documenting verified
    connections (DS18B20, SEN0189 divider, Adalogger SPI/I2C), and notes the
    schematic's LiPo + external-bq25185 power path and non-inverting
    turbidit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
    [scout-reva.kicad_sch]
2026-08-24 fix(firmware): correct PIN_TURBIDITY to match Rev A's A1 wiring
    SEN0189's TURB_DATA net lands on Feather A1 in the merged Rev A schematic;
    config.h and pin-assignments.md both defined PIN_TURBIDITY as A0, which is
    unconnected in Rev A. Isolated constant, single read site (turbidity.h).
    Refs SCO-85
    [config.h]
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2026-08-30 feat(mechanical): turbidity sensor housing face-seal remodel
    Reworked the body-to-cap joint into a proper static face seal: the
    AS568-137 O-ring sits in a single continuous face groove with the mating
    PETG faces designed to fully touch (hard stop) at full assembly, so the
    squeeze % is set by geometry, not fastener torque.
    Separately reinforced the bolt flanges so bolt-flange bowing/bending
    between the 3 bolts no longer locally lifts the groove face and drops the
    O-ring compression between the bolts.
    New STEP files (sensor-housing-body-face-seal.step, sensor-housing-
    sealed-cap.step) supersede the prior -current body/cap, which drop to
    Iteration in the README.
    Hub: design-notes row, journa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
    [sensor-housing-body-face-seal.step, sensor-housing-sealed-cap.step]
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2026-09-01 fix(firmware): move the LoRa modem to an FCC-compliant BW500/SF12 config (#120)
    The radio transmitted on a single fixed 915.0 MHz channel at 125 kHz and
    +14 dBm, which satisfies neither route 47 CFR 15.247 allows in 902-928:
    digital modulation needs a 6 dB bandwidth of at least 500 kHz, and the
    hopping route needs at least 50 channels. SCO-19's investigation found
    BW125 was never the safe default the previous driver comment assumed --
    that comment deliberately left SF at 7 pending this exact question.
    Widening to 500 kHz takes the digital-modulation route, which carries no
    dwell limit, which in turn frees the spreading factor. SF12's processing
    gain more than repays the 6 dB noise-bandwidth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
    [config.h, receiver.py]
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2026-09-01 fix(firmware): drop TX power to +11 dBm to stay inside the module's FCC grant (#122)
    The RFM95C on the Feather M0 carries FCC ID 2ASEORFM95C, a Single Modular
    Approval certifying 0.0145 W conducted -- 11.6 dBm. The firmware set +14,
    about 2.4 dB over, and FCC modular-approval rules put the burden on the
    integrator to keep power and transmission parameters inside the certified
    envelope or lose the approval.
    The same grant answers yesterday's open question and settles it in favour
    of the change already made: equipment class is DTS, the 15.247(a)(2)
    digital-modulation route. BW500 is the mode the module is certified in,
    BW125 single-channel was outside it, and the rejected hopping option would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
    [config.h]
2026-09-03 feat(mechanical): electronics housing static face-seal clamp
    Move the electronics housing's sealing fasteners outside the O-ring
    boundary. The 2026-08-21 design panel review found that fasteners sitting
    inside the seal turn every one into a leak path (SCO-68); this clamp puts
    all six on a Ø104.14 mm bolt circle, ~6.2 mm outboard of the groove OD, so
    none pierces the sealed region — and the bolt-joint sealing washers the
    prior design leaned on (and whose absence sank the 2026-08-24 submersion
    article) stop being load-bearing for waterproofing.
    Groove is cut to a standard AS568-043 ring rather than an arbitrary size:
    22.9 % squeeze, 75 % gland fill, both inside standard static-face-seal
    pr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
    [electronics-housing-clamp-v2-body.step, electronics-housing-clamp-v2-lid.step, sensor-housing-sealed-cap-v2.step]
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2026-09-09 feat(mechanical): add v5 wedge STEP, re-confirm turbidity housing CAD
    - chassis-floatation-bolted-v5-wedge.step committed (top level, not
    current/ — v5 chassis/caps and a dimensioned PDF still pending). STEP
    confirms the SCO-110 resize: 8.00 -> 5.50 in height, R9 outer
    unchanged, ~2x the B-rep face count from the added internal web +
    lightening holes. John's addition: the web is now a perforated
    compliant panel between the bolt flanges for chassis-fit flex and
    service access.
    - Turbidity sensor housing: John re-exported the sealed cap + no-port
    body; both byte-identical geometry to the committed -v2 cap and
    face-seal body, so no new files. Confirms them as current (and the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
    [chassis-floatation-bolted-v5-wedge.step]
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2026-09-10 fix(analytics): guard time-based analysis against a failed RTC, and add a real LoRa backend (#136)
    * fix(analytics): exclude clock-invalid rows from every time-based figure
    The firmware already degrades correctly when the PCF8523 fails: it sets
    RTC_LOST, stamps 1970-01-01, and keeps logging, because the sensor readings
    are still real even when the time is not. The analytics side had no matching
    guard, so it took those timestamps literally.
    One such row against a day of good data moved the deployment span to
    fifty-six years. Completeness went 100% -> 0.0%, expected records went
    48 -> 993,504, and a phantom 1970 day entered the daily series, dragging
    DHW, trends, and the drift screen with it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
    [link.py, radio.py, receiver.py]
2026-09-10 fix(shore): give real telemetry a publish path and a service that survives reboots (#137)
    DHW, trends, and the drift screen with it. Verifie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
    [publish.py, service.py]
2026-09-10 feat(shore): merge retrieved SD cards, and settle the acoustic stack on ARM (#138)
    DHW, trends, and the drift screen with it. Verified again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
    [sd_import.py]
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2026-09-29 feat(mechanical): add the buoy stability calculator and log the capsize/ballast design work
    The capsize finding, the ballast-arm hardware and the flange housing were only partly in the
    repo, and the calculators that produced them lived in a scratchpad. Committing the calculator
    (with dated results and an interactive explorer) makes every number re-runnable, and marks the
    newest results folder as current. Also records the ballast-arm decisions and part options, the
    flange-style housing sizing, the v6 assembly STEP, and the Hub entries.
    [ballast-depth.csv, cap-comparison.csv, current-mass-budget.csv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]
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2026-10-06 fix(docs): make the Gantt dependencies match Linear exactly and validate the plan
    An audit against every issue's Linear relations found wrong or missing
    dependencies in the chart (for example SCO-91, SCO-73, SCO-12, SCO-47, SCO-117,
    SCO-76, SCO-122). The CSV now mirrors Linear's blocked-by relations, dates
    follow them, and make_gantt.py refuses to print an inconsistent plan.
    [wbs-tasks.csv]
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2026-10-07 docs(mechanical): log the ribbed 6-bolt turbidity pod after the RR-14 leak
    The PLA pod leaked in the water; the redesign adds six bolts, a thicker cap and thicker ribs.
    [sensor-housing-assembly-v9.step]
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2026-10-08 docs(mechanical): close SCO-109, the sensor pod cap no longer has a spigot
    John removed the pilot spigot in the ribbed 6-bolt design, so the fit question is moot.
    [wbs-tasks.csv]
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2026-10-08 docs(docs): record the 4.4 x 5 in housing and the mechanical issues closed 2026-10-08
    Housing size was still TBD in facts.md; status and the Gantt still showed the closed chassis, mass model, stability, load-path and failure-case issues as open or blocked.
    [wbs-tasks.csv]
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

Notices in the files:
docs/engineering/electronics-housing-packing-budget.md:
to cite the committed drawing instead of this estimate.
